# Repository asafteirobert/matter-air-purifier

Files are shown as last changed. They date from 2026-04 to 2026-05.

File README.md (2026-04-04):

# Matter Air Purifier

Firmware for a CRBox air purifier built around the Seeed Studio XIAO ESP32C6. Controllable via **Matter over Thread**. Integrates well and can be commissioned in Home Assistant. Since the device is not certified, commissioning with other platforms such as Apple Home and Google Home likely does not work directly.

> For an experimental version without Matter that hosts a local web server with a web UI, see the [standalone-mode](../../tree/standalone-mode) branch.

## Hardware

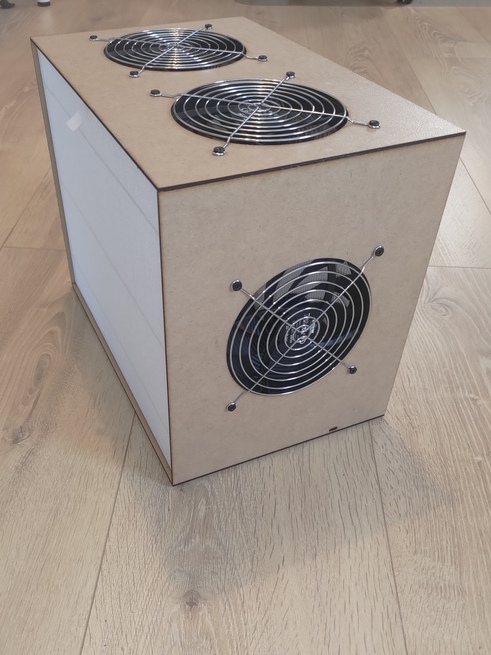
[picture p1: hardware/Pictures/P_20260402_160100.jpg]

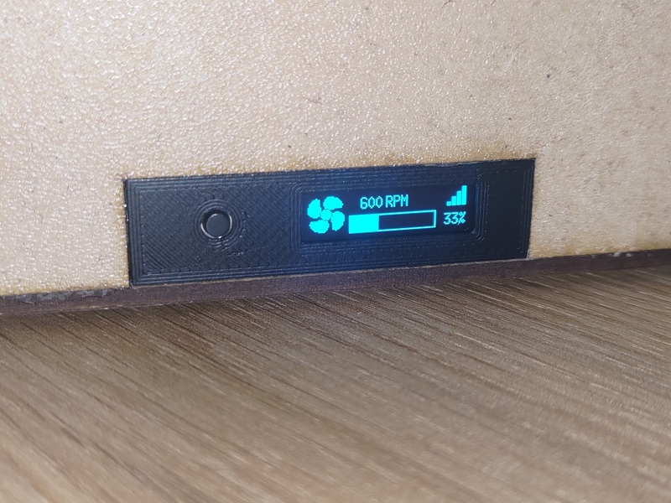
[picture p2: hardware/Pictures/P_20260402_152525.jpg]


The CRBox is designed for 2 IKEA STARKVIND filters. It has 3 **140mm BeQuiet Pure Wings 3 High Speed** fans which offer extremely quiet operation at low speeds.
The case is made from laser-cut MDF and smoothed 7mm pine strips, glued with epoxy. A small 3D printed part is used as a front panel. It's powered though USB C. It requires a 12V capable USB-PD power supply (IKEA 20W SJÖSS works great).

## Performance
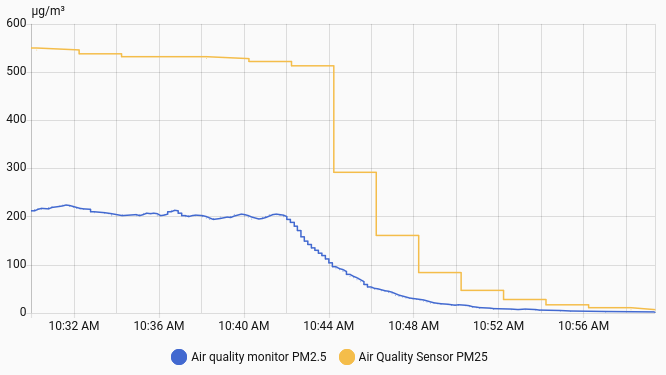
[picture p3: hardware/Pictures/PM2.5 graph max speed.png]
PM2.5 graph at 100% speed


Limited testing shows the Air Purifier can bring an extremely polluted room from ~400 ug/m3 PM2.5 to <10 ug/m3
- in 4 hours at 12% speed.
- in 53 minutes at 50% speed.
- in 17 minutes at 100% speed.

## Making your own
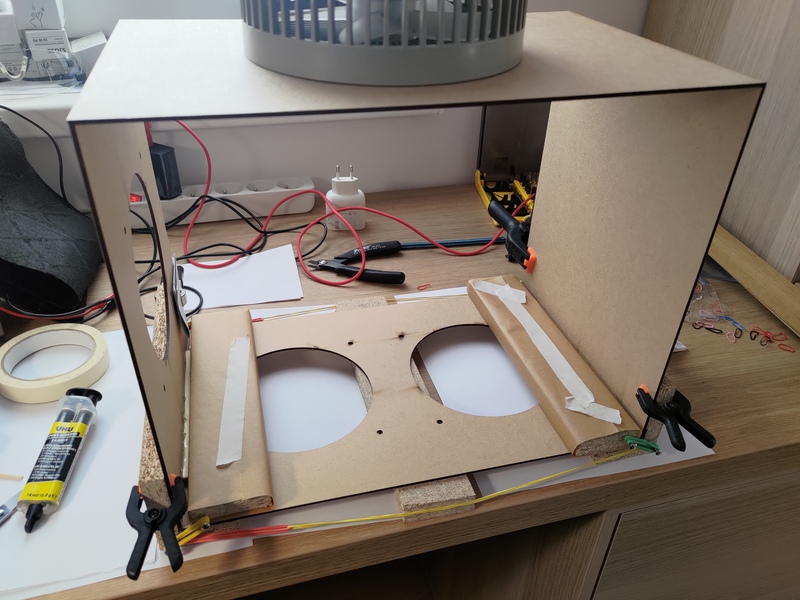
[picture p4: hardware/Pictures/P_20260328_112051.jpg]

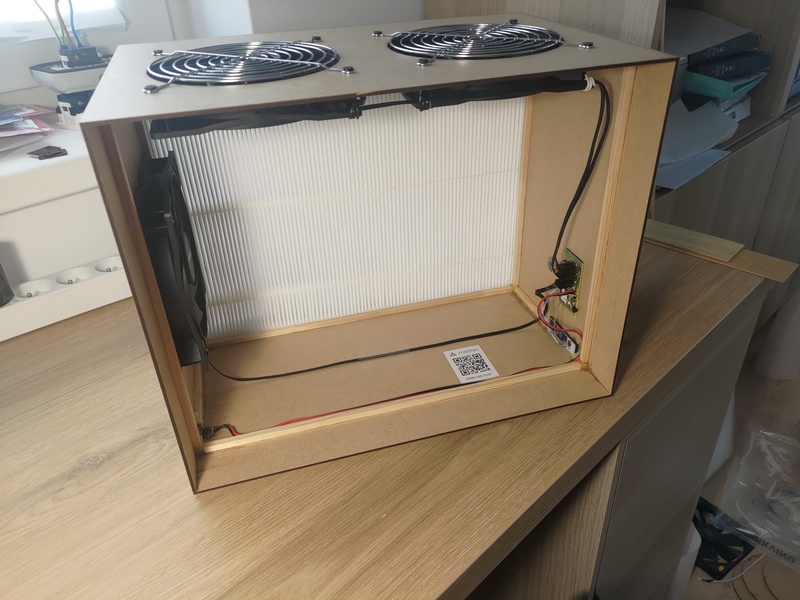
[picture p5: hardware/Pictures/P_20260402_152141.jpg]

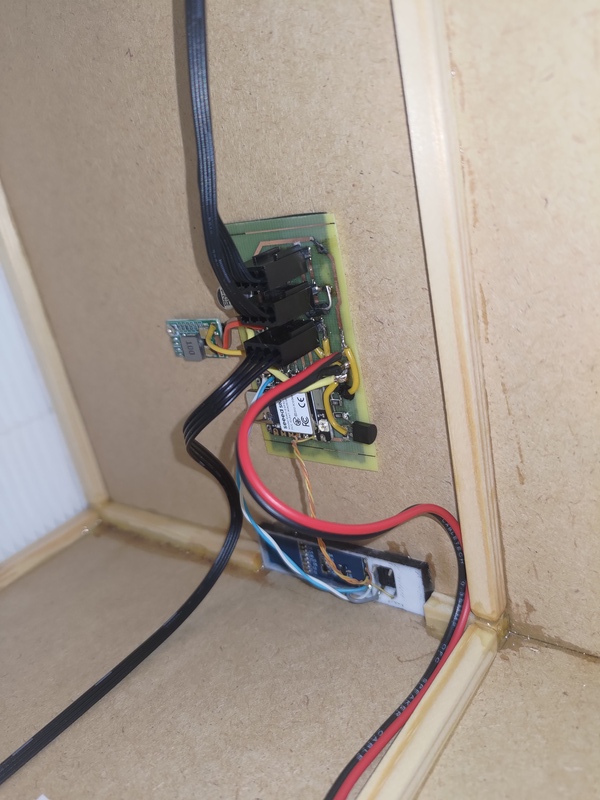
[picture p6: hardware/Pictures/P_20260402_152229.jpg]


This is a hobby project. I'm sharing this to serve as inspiration for anyone that wants to build something similar. Assembly is quite involved and I'm not providing step by step instructions but I'm sharing all the relevant files. See [hardware](hardware/)

## Features

- **Matter Air Purifier device type** — Fan Control cluster with Off/Low/Medium/High modes and 0–100% speed control
- **3-fan control** — PWM speed control (25 kHz) with per-fan RPM tachometer feedback
- **OLED display** — 128×32 screen showing fan speed, RPM, signal bars, QR code for commissioning, and info/reset screens
- **Physical buttons** — Short press toggles Off/Low/Medium/High; 2 second long press shows info screen. 8 second long press triggers factory reset.
- **Thread-only** — Runs on the ESP32-C6's 802.15.4 radio; WiFi disabled (see [Enabling WiFi](#enabling-wifi-alongside-thread))
- **OTA updates** — Firmware updates via Home Assistant Matter Server
- **Factory NVS partition** — Stores per-device commissioning codes, QR codes

## Commissioning

Use the scripts in `mfg-tool-scripts/` to generate and flash per-device commissioning data:

```bash
./0_clean.sh      # remove previous outputs
./1_generate.sh   # generate new commissioning data
./2_add_qrcode.sh # embed QR and manual pairing codes
./3_flash.sh      # flash to device (default port: /dev/ttyACM0)
```

Override the port: `PORT=/dev/ttyUSB0 ./3_flash.sh`.

Commissioning QR code and manual code will be shown on the tiny screen when the commissioning window is open, but it will be hard to scan. A png of the QR code can be found in `mfg-tool-scripts/out/fff1_8002/<hash>/<hash>-qrcode.png`

## OTA Update via Home Assistant Matter Server

1. Bump `CONFIG_DEVICE_SOFTWARE_VERSION` / `CONFIG_DEVICE_SOFTWARE_VERSION_NUMBER` in `sdkconfig.defaults.esp32c6`
2. Bump `PROJECT_VER` / `PROJECT_VER_NUMBER` in `CMakeLists.txt`
3. Build and compute the OTA checksum:
   ```bash
   openssl dgst -sha256 -binary matter-air-purifier-ota.bin | base64
   ```
4. Copy `matter-air-purifier-ota.bin` to:
   `/addon_configs/core_matter_server/updates/matter-air-purifier-ota.ota`
5. Create `matter-air-purifier-ota.json`:
   ```json
   {
     "modelVersion": {
       "vid": 65521,
       "pid": 32769,
       "softwareVersion": <VERSION>,
       "softwareVersionString": "<VERSION STRING>",
       "cdVersionNumber": 1,
       "softwareVersionValid": true,
       "otaUrl": "file:///matter-air-purifier-ota.ota",
       "otaChecksum": "<CHECKSUM>",
       "otaChecksumType": 1,
       "minApplicableSoftwareVersion": 0,
       "maxApplicableSoftwareVersion": <PREVIOUS VERSION>,
       "releaseNotesUrl": ""
     }
   }
   ```
6. Trigger the update from the Matter Server web UI by selecting the node in the sidebar.

## Enabling WiFi alongside Thread

The ESP32-C6 has separate radios for 802.15.4 (Thread) and WiFi, so both can run simultaneously. WiFi is disabled by default because it increases RAM/flash usage and the WiFi radio stays powered even when idle (no credentials commissioned).

To enable WiFi as a secondary network interface:

1. In `sdkconfig.defaults.esp32c6`, change:
   ```
   CONFIG_ENABLE_WIFI_STATION=n
   ```
   to:
   ```
   CONFIG_ENABLE_WIFI_STATION=y
   ```

2. Switch mDNS to the platform implementation (required for Thread DNS-SD):
   ```
   CONFIG_USE_MINIMAL_MDNS=n
   ```
   > **Note:** The platform mDNS backend (`ESP32DnssdImpl.cpp`) currently has build errors (ignored `CHIP_ERROR` returns treated as fatal by `-Werror`). If the build fails, set `CONFIG_USE_MINIMAL_MDNS=y` as a workaround until the upstream SDK is fixed.

3. Rebuild and reflash.

## AI Disclaimer
This project was coded with heavy use of Claude Code

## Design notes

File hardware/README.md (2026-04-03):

# Hardware

- **3D model** can be seen [here](https://a360.co/4dngQW1). Free license does not allow me to export it.
- **[Laser cut](Laser%20cut/)** — DXF files to laser cut the 2.5mm MDF boards making most of the body. Using a different thickness means some dimensions will change.
- **[Schematic](Schematic/)** — Schematic, PCB and EasyEDA Pro project. The PCB was manufactured at home with only the top side, so some connections use wires. This is why some of the routing, large vias and DRC rules look strange.
- **[Front Panel](Front%20Panel/)** — 3D model to be 3D printed, that slots in the front panel. It has slots for a microswitch and a common 128x32 OLED display.
- **[Pictures](Pictures/)** — Photos of the hardware.

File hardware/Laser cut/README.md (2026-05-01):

**[version 1](version%201/)** contains the first version, visible in the pictures with the fan on the back. The latest version has the fan in the front.

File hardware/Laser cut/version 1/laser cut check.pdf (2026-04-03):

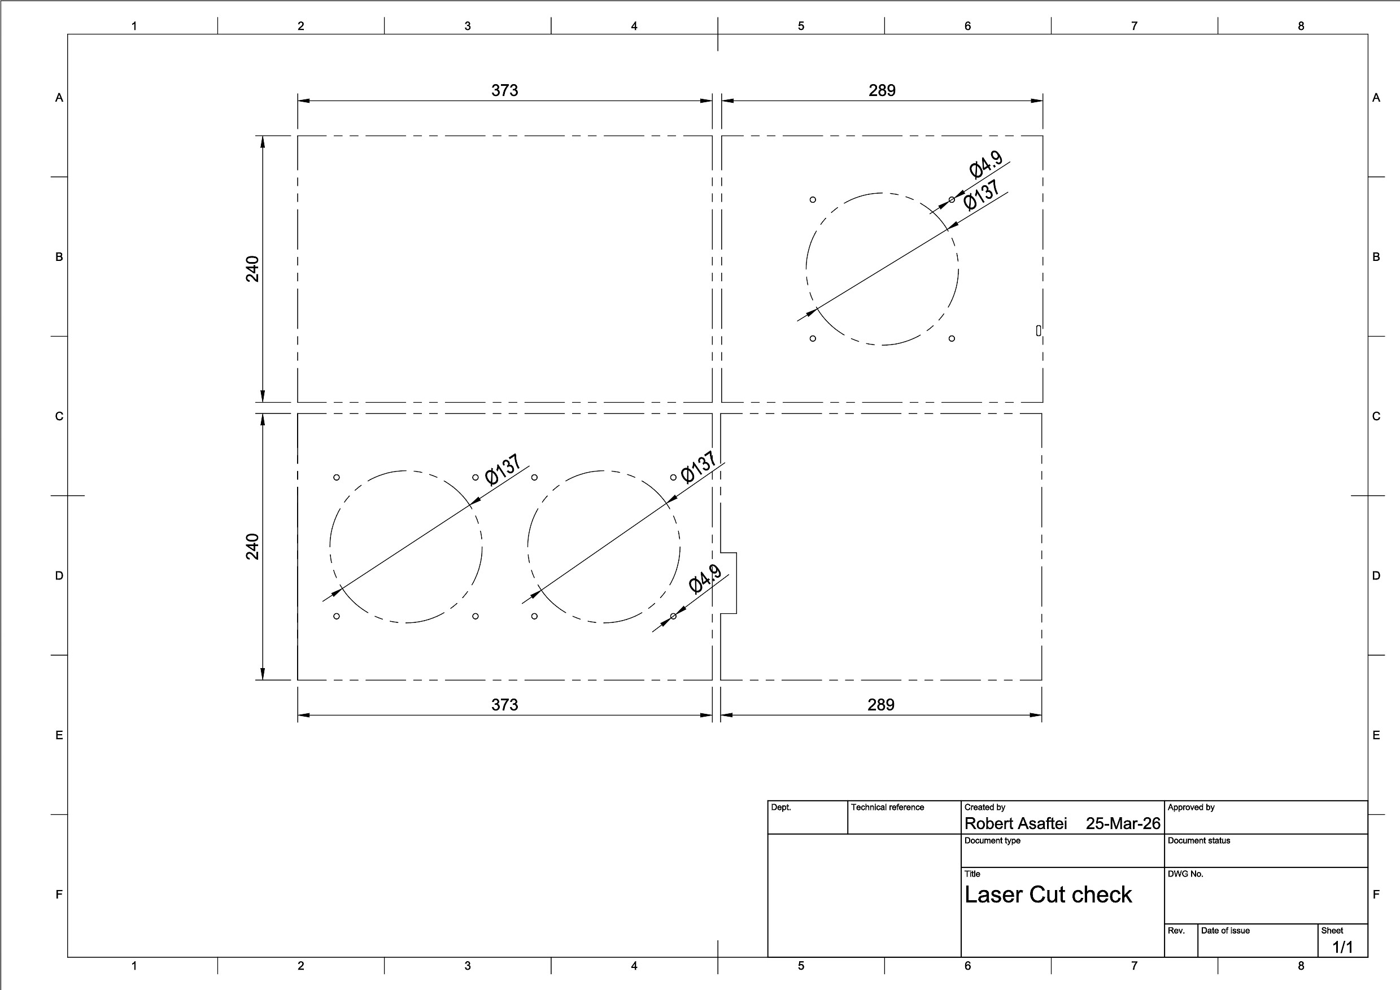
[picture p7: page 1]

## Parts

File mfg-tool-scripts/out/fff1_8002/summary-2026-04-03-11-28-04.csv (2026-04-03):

discriminator | iteration-count | salt | vendor-id | vendor-name | product-id | product-name | hardware-ver | hw-ver-str | serial-num | verifier | pincode | qrcode | manualcode
2458 | 10000 | CpgTCc8W+Rcqdphdbbo67YKkOLRqsWQs+q+SB6Ub92I= | 65521 | Twinsen | 32770 | Air Purifier | 1 | 01 | d155618ca8cd4e3e44d1683ac4f1faaf | hWKX0owqHqvmHICCKsJPmoxauj6mCclDcPf6ccEDxU0ENnAkcprttOtbRf4fQ4uoTI6fEox0D49rsdVOc2k7ParbnqoPTJrCTLCj90Uca5rc46i5cfkHWGtDyjAfElME3g== | 96988228 | MT:06PS0KQS02RINU6X120 | 2277-165-9195

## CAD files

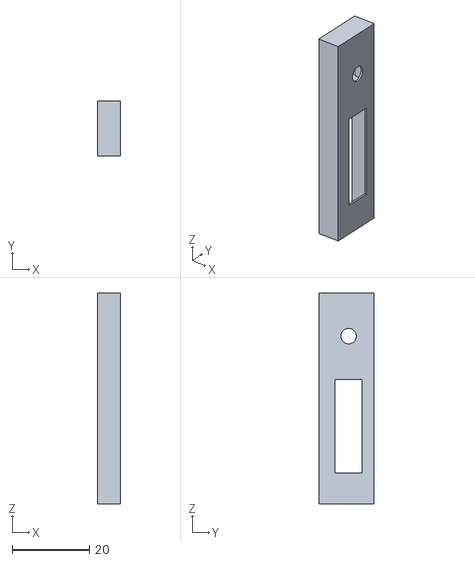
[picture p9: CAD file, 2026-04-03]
hardware/Front Panel/CRBox Front Panel.stl
6.00 x 14.2 x 54.6

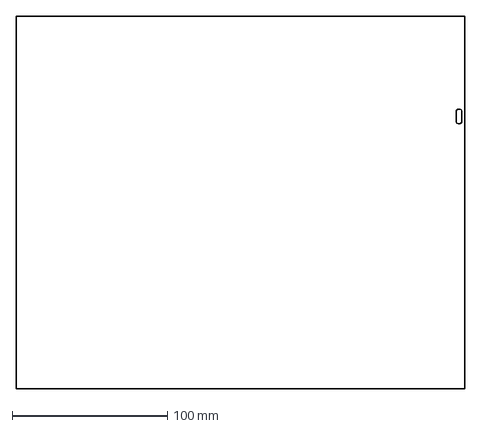
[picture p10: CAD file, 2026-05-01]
hardware/Laser cut/laser cut left.dxf
289.0 x 240.0 mm

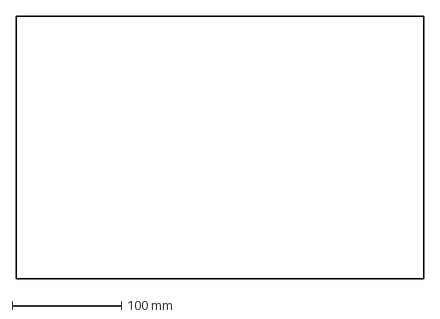
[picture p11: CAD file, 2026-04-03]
hardware/Laser cut/version 1/laser cut bottom.dxf
373.0 x 240.0 mm

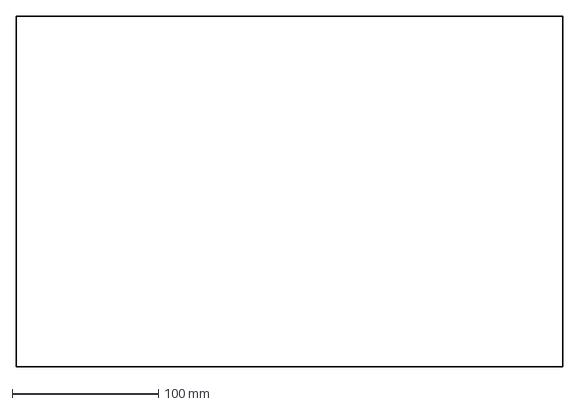
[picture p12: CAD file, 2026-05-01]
hardware/Laser cut/laser cut bottom.dxf
374.0 x 240.0 mm

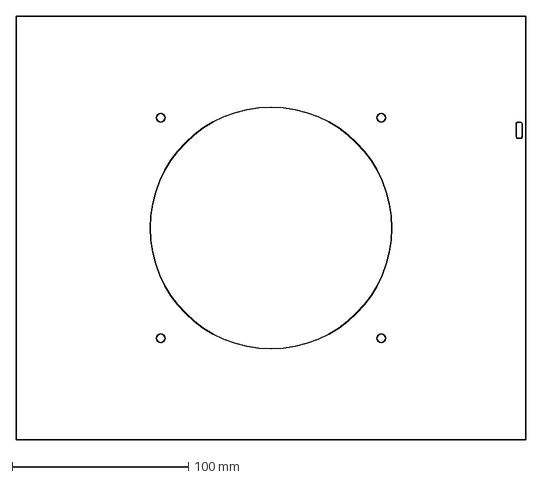
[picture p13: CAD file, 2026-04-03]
hardware/Laser cut/version 1/laser cut left.dxf
289.0 x 240.0 mm

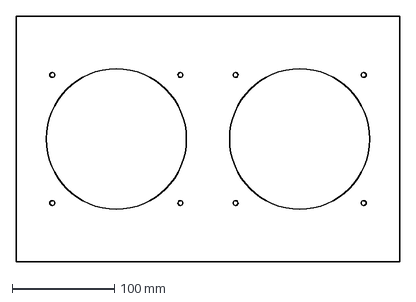
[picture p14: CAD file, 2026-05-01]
hardware/Laser cut/laser cut top.dxf
374.0 x 240.0 mm

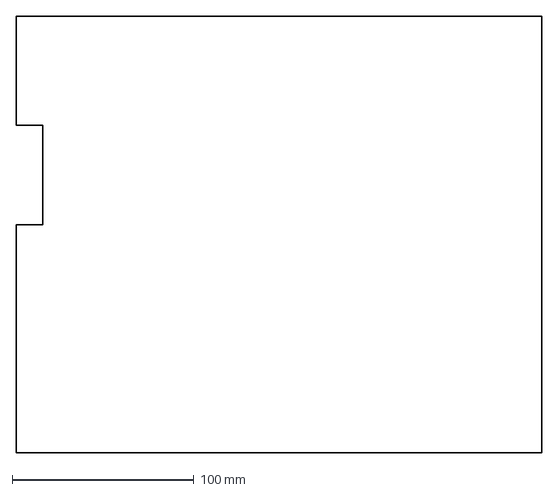
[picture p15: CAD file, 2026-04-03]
hardware/Laser cut/version 1/laser cut right.dxf
289.0 x 240.0 mm

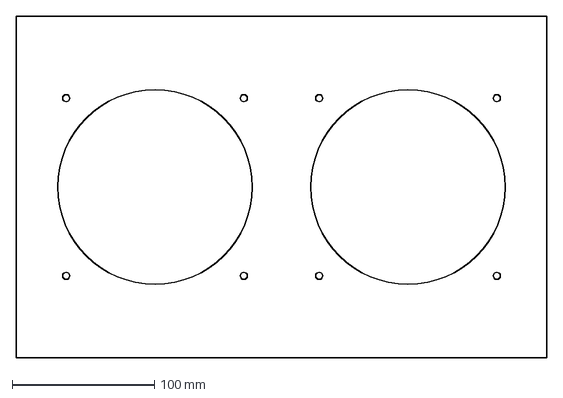
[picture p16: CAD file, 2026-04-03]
hardware/Laser cut/version 1/laser cut top.dxf
373.0 x 240.0 mm

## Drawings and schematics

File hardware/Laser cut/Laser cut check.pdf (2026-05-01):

240

# 240 Ø137 Ø137 Ø4.9

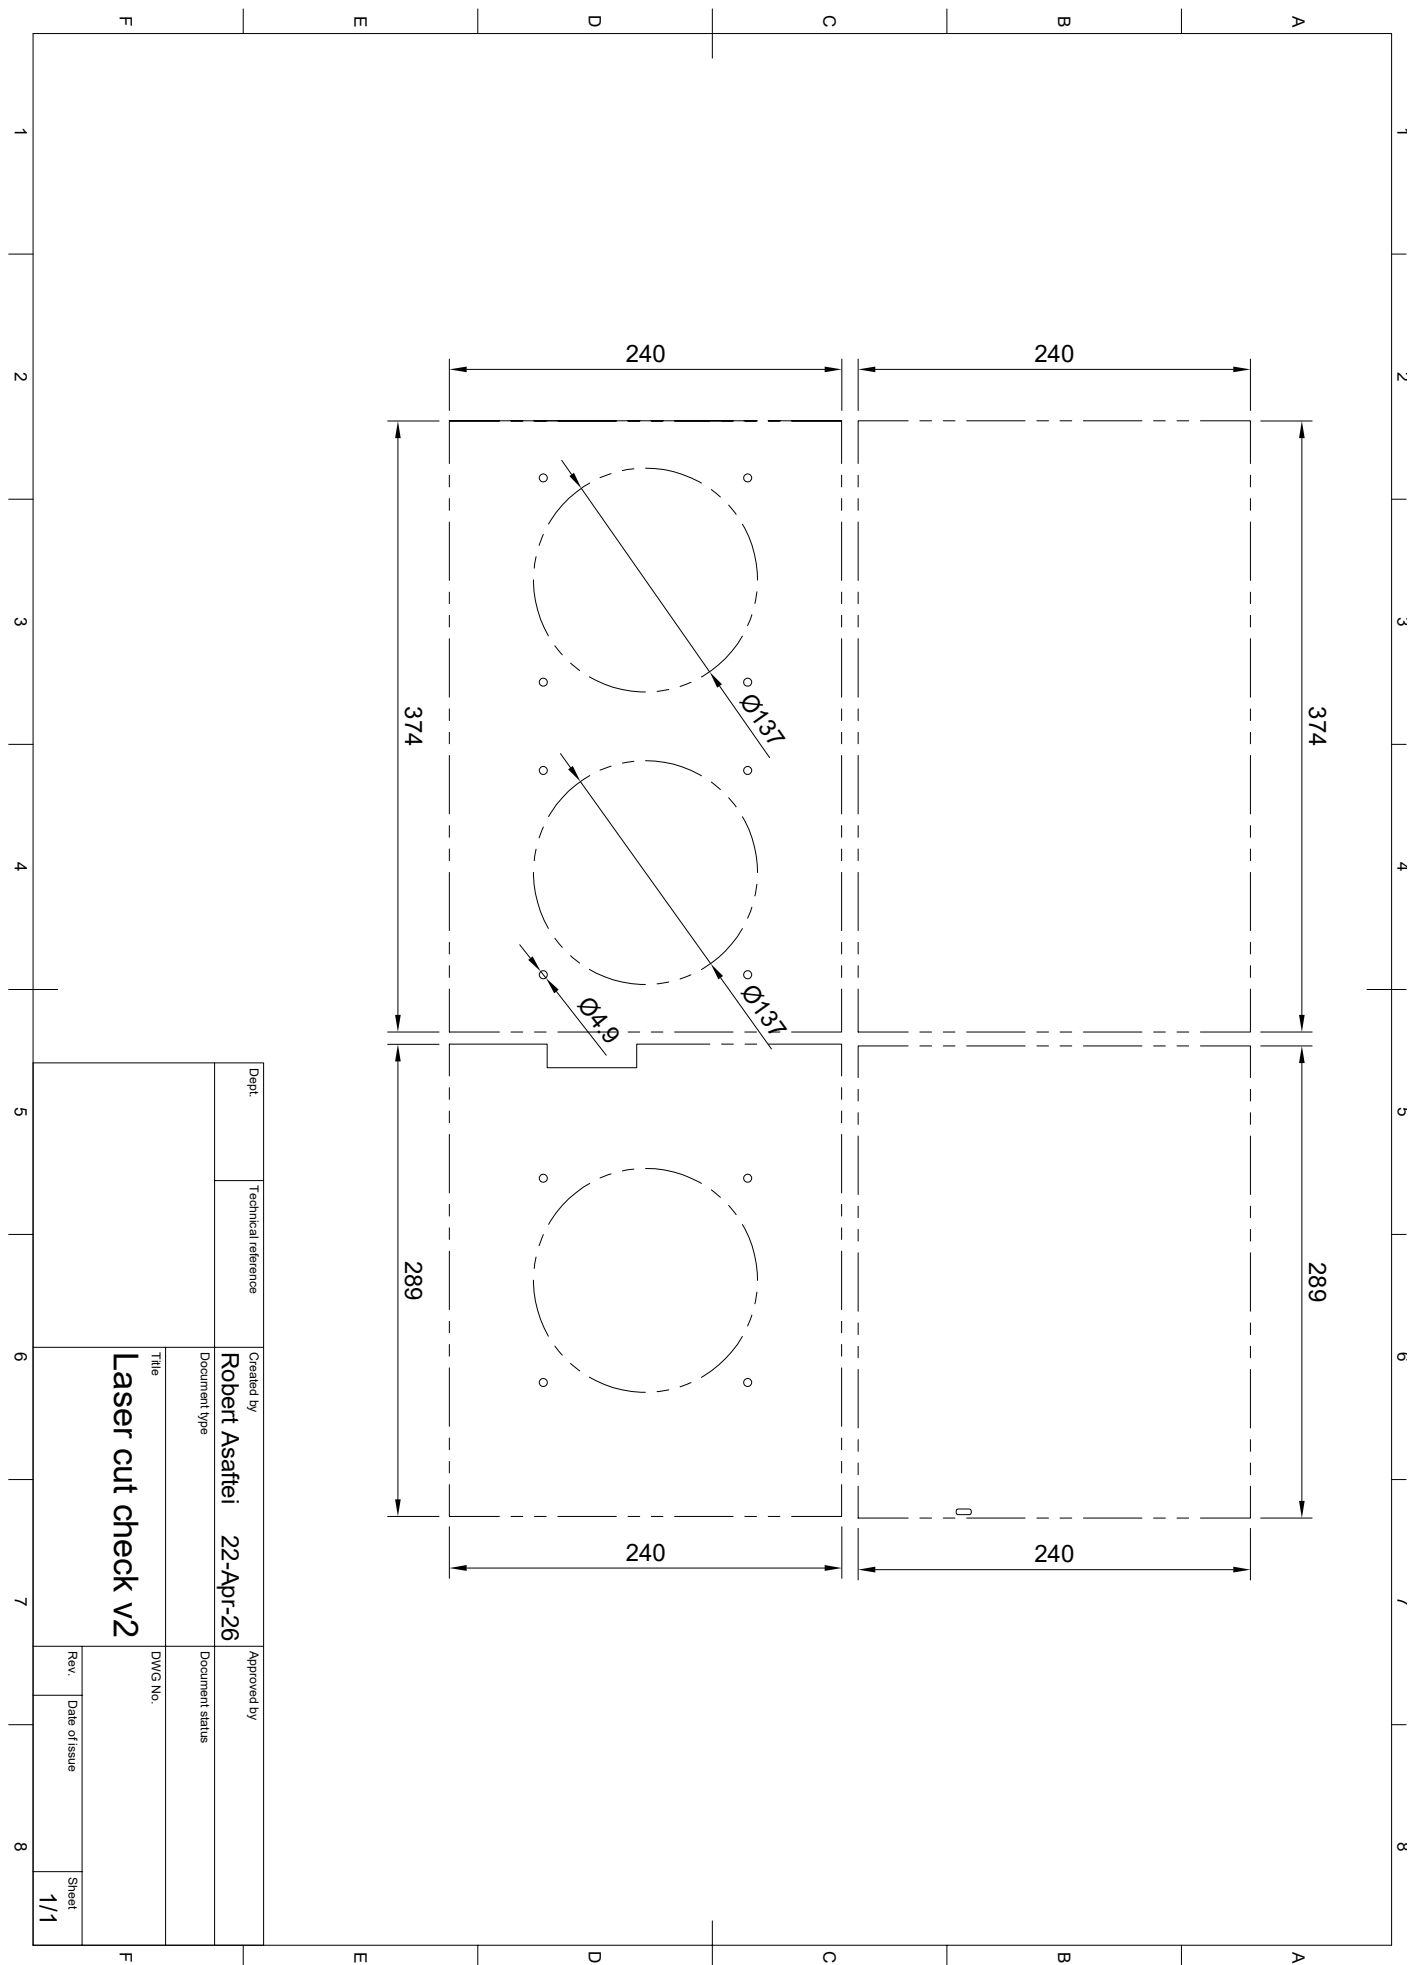
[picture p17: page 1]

1 A 2 3 4 5 6 7 8 1 2 3 4 5 6 7 8 FEDCB FEDCBA Dept. Technical reference Created by Approved by Title DWG No. Document type Document status Rev. Date of issue Sheet 22-Apr-26 1/1 Laser cut check v2 Robert Asaftei 374 289

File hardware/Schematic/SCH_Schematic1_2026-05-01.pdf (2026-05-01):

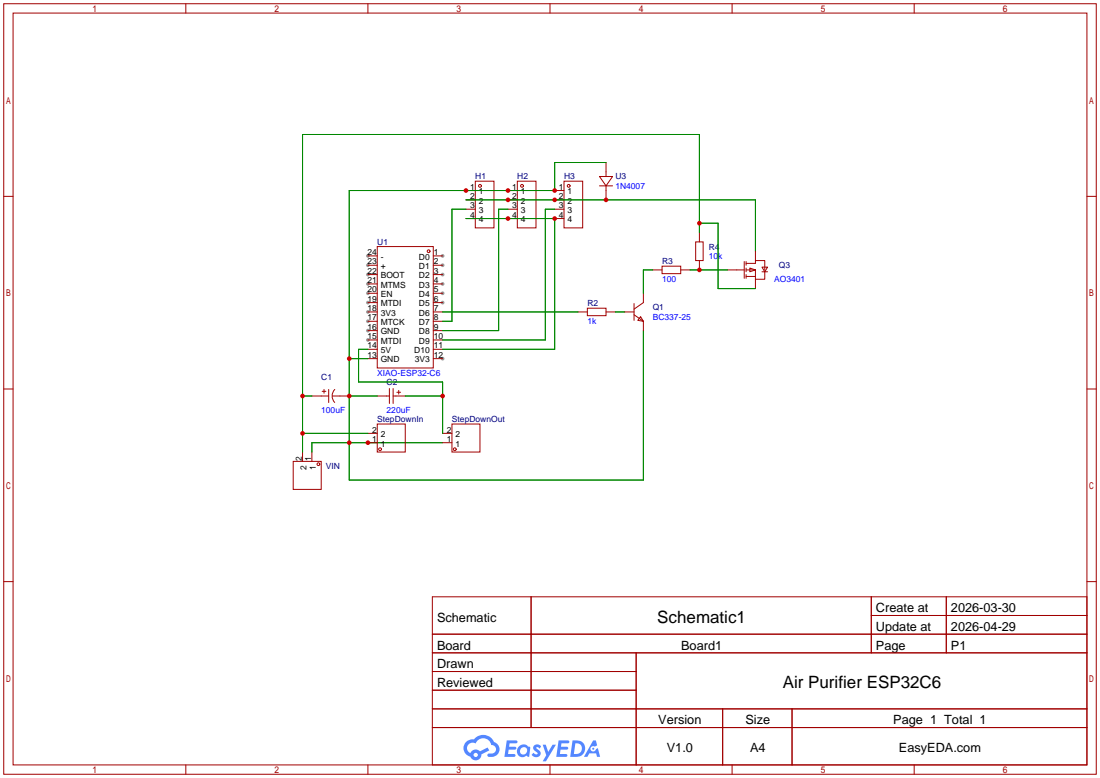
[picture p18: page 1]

3V3 12 GND 13 5V 14 MTDI 15 GND 16 MTCK 17 3V3 18 MTDI 19 EN 20 MTMS 21 BOOT 22 +

Schematic | Schematic1 | Create at | 2026-03-30

Update at | 2026-04-29

Board | Board1 | Page | P1
Drawn | | Air Purifier ESP32C6
Reviewed

Version | Size | Page 1 Total 1
V1.0 | A4 | EasyEDA.com

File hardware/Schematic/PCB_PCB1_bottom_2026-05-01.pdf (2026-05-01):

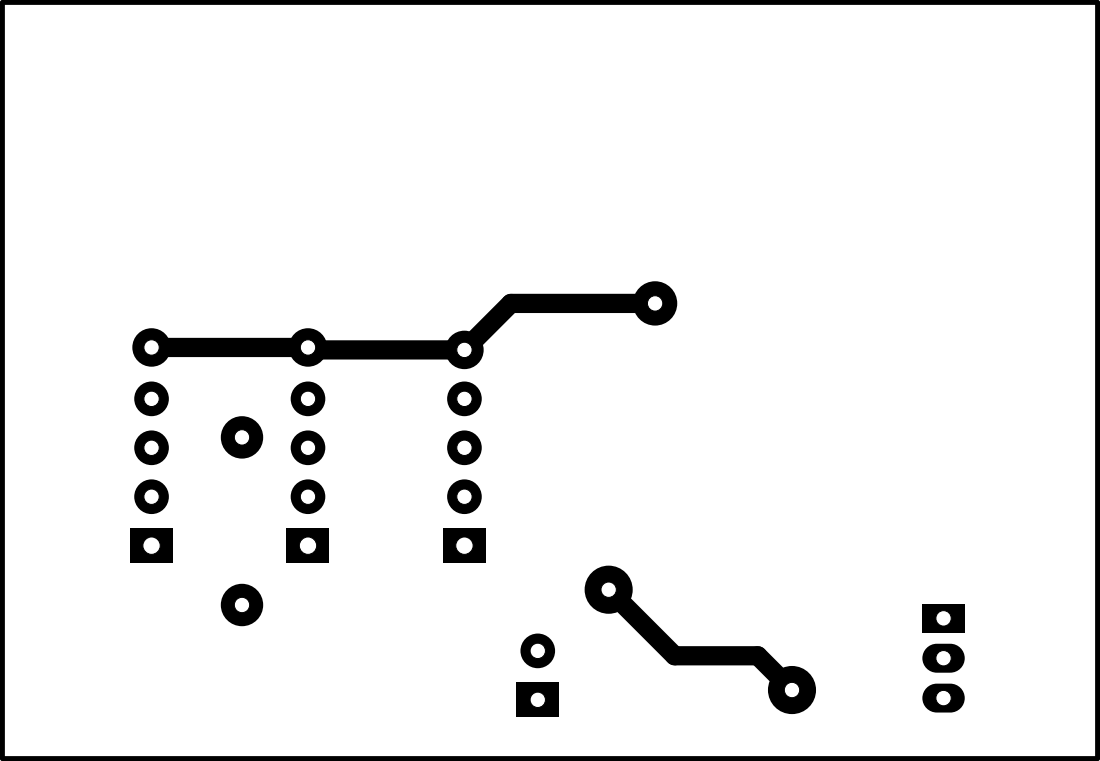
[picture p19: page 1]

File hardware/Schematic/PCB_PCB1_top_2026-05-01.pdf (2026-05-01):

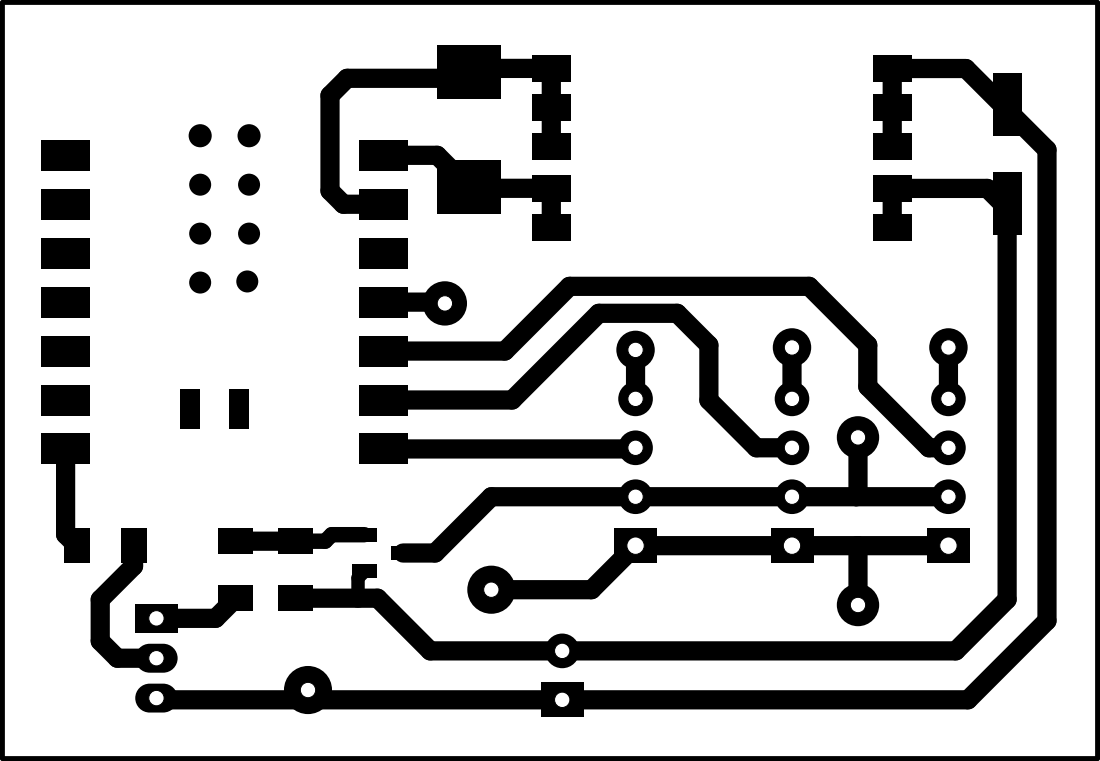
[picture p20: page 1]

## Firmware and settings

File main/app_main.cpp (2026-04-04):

#include <esp_err.h>
#include <esp_log.h>
#include <nvs_flash.h>
#include "freertos/FreeRTOS.h"
#include "freertos/task.h"

#include <esp_matter.h>
#include <esp_matter_console.h>
#include <esp_matter_ota.h>

#include "CliCommands.hpp"

#include "ButtonDriver.hpp"
#include "FanDriver.hpp"
#include "DisplayDriver.hpp"

#include "Utils.hpp"

#if CHIP_DEVICE_CONFIG_ENABLE_THREAD
#include <platform/ESP32/OpenthreadLauncher.h>
#include <esp_openthread.h>
#include <esp_openthread_lock.h>
#include <openthread/thread.h>
#endif

#include "esp_timer.h"

#include <app/server/CommissioningWindowManager.h>
#include <app/server/Server.h>
#include <nvs.h>

#ifdef CONFIG_ENABLE_SET_CERT_DECLARATION_API
#include <esp_matter_providers.h>
#include <lib/support/Span.h>
#ifdef CONFIG_SEC_CERT_DAC_PROVIDER
#include <platform/ESP32/ESP32SecureCertDACProvider.h>
#elif defined(CONFIG_FACTORY_PARTITION_DAC_PROVIDER)
#include <platform/ESP32/ESP32FactoryDataProvider.h>
#endif
using namespace chip::DeviceLayer;
#endif

using namespace esp_matter;
using namespace esp_matter::attribute;
using namespace esp_matter::endpoint;
using namespace chip::app::Clusters;

static const char *TAG = "app_main";
constexpr auto k_timeout_seconds = 300;

ButtonDriver buttonDriver;
FanDriver fanDriver;
DisplayDriver displayDriver;

#ifdef CONFIG_ENABLE_SET_CERT_DECLARATION_API
extern const uint8_t cd_start[] asm("_binary_certification_declaration_der_start");
extern const uint8_t cd_end[] asm("_binary_certification_declaration_der_end");

const chip::ByteSpan cdSpan(cd_start, static_cast<size_t>(cd_end - cd_start));
#endif // CONFIG_ENABLE_SET_CERT_DECLARATION_API

#if CONFIG_ENABLE_ENCRYPTED_OTA
extern const char decryption_key_start[] asm("_binary_esp_image_encryption_key_pem_start");
extern const char decryption_key_end[] asm("_binary_esp_image_encryption_key_pem_end");

static const char *s_decryption_key = decryption_key_start;
static const uint16_t s_decryption_key_len = decryption_key_end - decryption_key_start;
#endif // CONFIG_ENABLE_ENCRYPTED_OTA

static void app_event_cb(const ChipDeviceEvent *event, intptr_t arg)
{
    switch (event->Type) 
    {
    case chip::DeviceLayer::DeviceEventType::kInterfaceIpAddressChanged:
        ESP_LOGI(TAG, "Interface IP Address changed");
        break;

    case chip::DeviceLayer::DeviceEventType::kCommissioningComplete:
        if (displayDriver.getActiveScreen() == DisplayDriver::Screen::Comission)
            displayDriver.setActiveScreen(DisplayDriver::Screen::Main);
        ESP_LOGI(TAG, "Commissioning complete");
        break;

    case chip::DeviceLayer::DeviceEventType::kFailSafeTimerExpired:
        ESP_LOGI(TAG, "Commissioning failed, fail safe timer expired");
        break;

    case chip::DeviceLayer::DeviceEventType::kCommissioningSessionStarted:
        ESP_LOGI(TAG, "Commissioning session started");
        break;

    case chip::DeviceLayer::DeviceEventType::kCommissioningSessionStopped:
        ESP_LOGI(TAG, "Commissioning session stopped");
        break;

    case chip::DeviceLayer::DeviceEventType::kCommissioningWindowOpened:
    {
        displayDriver.setActiveScreen(DisplayDriver::Screen::Comission);
        ESP_LOGI(TAG, "Commissioning window opened");
        break;
    }

    case chip::DeviceLayer::DeviceEventType::kCommissioningWindowClosed:
    {
        if (displayDriver.getActiveScreen() == DisplayDriver::Screen::Comission)
            displayDriver.setActiveScreen(DisplayDriver::Screen::Main);
        ESP_LOGI(TAG, "Commissioning window closed");
        break;
    }

    case chip::DeviceLayer::DeviceEventType::kFabricRemoved: 
    {
        ESP_LOGI(TAG, "Fabric removed successfully");
        if (chip::Server::GetInstance().GetFabricTable().FabricCount() == 0) 
        {
            chip::CommissioningWindowManager  &commissionMgr = chip::Server::GetInstance().GetCommissioningWindowManager();
            constexpr auto kTimeoutSeconds = chip::System::Clock::Seconds16(k_timeout_seconds);
            if (!commissionMgr.IsCommissioningWindowOpen())
            {
                /* After removing last fabric, we do not remove the Wi-Fi credentials
                 * and still has IP connectivity so, only advertising on DNS-SD.
                 */
                CHIP_ERROR err = commissionMgr.OpenBasicCommissioningWindow(kTimeoutSeconds,
                                                                            chip::CommissioningWindowAdvertisement::kDnssdOnly);
                if (err != CHIP_NO_ERROR)
                {
                    ESP_LOGE(TAG, "Failed to open commissioning window, err:%" CHIP_ERROR_FORMAT, err.Format());
                }
            }
        }
        break;
    }

    case chip::DeviceLayer::DeviceEventType::kFabricWillBeRemoved:
        ESP_LOGI(TAG, "Fabric will be removed");
        break;

    case chip::DeviceLayer::DeviceEventType::kFabricUpdated:
        ESP_LOGI(TAG, "Fabric is updated");
        break;

    case chip::DeviceLayer::DeviceEventType::kFabricCommitted:
        ESP_LOGI(TAG, "Fabric is committed");
        break;

    case chip::DeviceLayer::DeviceEventType::kBLEDeinitialized:
        ESP_LOGI(TAG, "BLE deinitialized and memory reclaimed");
        break;

    default:
        break;
    }
}

// This callback is invoked when clients interact with the Identify Cluster.
// In the callback implementation, an endpoint can identify itself. (e.g., by flashing an LED or light).
static esp_err_t app_identification_cb(identification::callback_type_t type, uint16_t endpoint_id, uint8_t effect_id,
                                       uint8_t effect_variant, void *priv_data)
{
    ESP_LOGI(TAG, "Identification callback: type: %u, effect: %u, variant: %u", type, effect_id, effect_variant);
    if (type == identification::START || type == identification::EFFECT)
    {
        displayDriver.setActiveScreen(DisplayDriver::Screen::Identify);
    }
    return ESP_OK;
}

/**
 * Called by the Matter stack BEFORE (PRE_UPDATE) and AFTER (POST_UPDATE) an
 * attribute is written.  We only need PRE_UPDATE to drive the hardware.
 */
static esp_err_t app_attribute_update_cb(attribute::callback_type_t type,
                                         uint16_t  endpoint_id,
                                         uint32_t  cluster_id,
                                         uint32_t  attribute_id,
                                         esp_matter_attr_val_t *val,
                                         void *priv_data)
{
    //ESP_LOGI(TAG, "app_attribute_update_cb type: %d, endpoint_id: %d, cluster_id: %d, attribute_id: %d, val.u8: %d", 
    //              type,
    //              endpoint_id, 
    //              cluster_id, 
    //              attribute_id, 
    //              (val) ? val->val.u8 : -1);

    return fanDriver.attributeUpdate(type, endpoint_id, cluster_id, attribute_id, val);
}

static void signalTimerCb(void * /*arg*/)
{
#if CHIP_DEVICE_CONFIG_ENABLE_THREAD
    if (esp_openthread_lock_acquire(pdMS_TO_TICKS(100)))
    {
        otInstance   *instance = esp_openthread_get_instance();
        otDeviceRole  role     = otThreadGetDeviceRole(instance);
        int8_t        rssi     = -120;
        bool          valid    = false;

        if (role == OT_DEVICE_ROLE_CHILD)
        {
            valid = (otThreadGetParentAverageRssi(instance, &rssi) == OT_ERROR_NONE);
        }
        else if (role == OT_DEVICE_ROLE_ROUTER || role == OT_DEVICE_ROLE_LEADER)
        {
            otNeighborInfoIterator it = OT_NEIGHBOR_INFO_ITERATOR_INIT;
            otNeighborInfo         info;
            while (otThreadGetNextNeighborInfo(instance, &it, &info) == OT_ERROR_NONE)
            {
                if (!info.mIsChild && info.mAverageRssi > rssi)
                    rssi = info.mAverageRssi;
            }
            valid = (rssi > -120);
        }

        esp_openthread_lock_release();

        //if (valid)
        //    ESP_LOGI(TAG, "Thread RSSI: %d dBm (role %d)", rssi, (int)role);
        //else
        //    ESP_LOGW(TAG, "Thread RSSI unavailable (role %d)", (int)role);

        DisplayDriver::ThreadRole displayRole;
        switch (role)
        {
            case OT_DEVICE_ROLE_CHILD:    displayRole = DisplayDriver::ThreadRole::Child;    break;
            case OT_DEVICE_ROLE_ROUTER:   displayRole = DisplayDriver::ThreadRole::Router;   break;
            case OT_DEVICE_ROLE_LEADER:   displayRole = DisplayDriver::ThreadRole::Leader;   break;
            case OT_DEVICE_ROLE_DETACHED: displayRole = DisplayDriver::ThreadRole::Detached; break;
            default:                      displayRole = DisplayDriver::ThreadRole::Disabled; break;
        }
        displayDriver.setThreadRole(displayRole);
        displayDriver.setSignal(rssi);
    }
#endif
}

extern "C" void app_main()
{
    esp_err_t err = ESP_OK;

    // Initialize the ESP NVS layer
    err = nvs_flash_init();
    if (err == ESP_ERR_NVS_NO_FREE_PAGES || err == ESP_ERR_NVS_NEW_VERSION_FOUND) {
        ESP_ERROR_CHECK(nvs_flash_erase());
        err = nvs_flash_init();
    }
    ESP_ERROR_CHECK(err);

    // Switch to internal antenna
    // Activate RF switch
    gpio_set_direction(ANTENNA_ENABLE_GPIO, GPIO_MODE_OUTPUT);
    gpio_set_level(ANTENNA_ENABLE_GPIO, 0); //active low

    // Select internal antenna
    gpio_set_direction(ANTENNA_CONFIG_GPIO, GPIO_MODE_OUTPUT);
    gpio_set_level(ANTENNA_CONFIG_GPIO, 0);

    displayDriver.init();
    displayDriver.drawSplashScreen();

    // Create a Matter node and add the mandatory Root Node device type on endpoint 0
    node::config_t node_config;

    // node handle can be used to add/modify other endpoints.
    node_t *node = node::create(&node_config, app_attribute_update_cb, app_identification_cb);
    ABORT_APP_ON_FAILURE(node != nullptr, ESP_LOGE(TAG, "Failed to create Matter node"));

    air_purifier::config_t air_purifier_config;
    air_purifier_config.fan_control.fan_mode          = (uint8_t)FanControl::FanModeEnum::kOff;
    air_purifier_config.fan_control.fan_mode_sequence = (uint8_t)FanControl::FanModeSequenceEnum::kOffLowMedHigh;

    endpoint_t *air_purifier_endpoint = air_purifier::create(node, &air_purifier_config, ENDPOINT_FLAG_NONE, nullptr);
    if (air_purifier_endpoint == nullptr)
    {
        ESP_LOGE(TAG, "Failed to create air purifier endpoint");
        return;
    }

    // Enable the MultiSpeed feature (required by Home Assistant for percentage control).
    // SpeedMax=100 makes SpeedSetting a direct 0-100 percentage.
    cluster_t *fan_cluster = cluster::get(air_purifier_endpoint, chip::app::Clusters::FanControl::Id);
    ABORT_APP_ON_FAILURE(fan_cluster != nullptr, ESP_LOGE(TAG, "Failed to get FanControl cluster"));
    cluster::fan_control::feature::multi_speed::config_t multispeed_config;
    multispeed_config.speed_max     = 100;
    multispeed_config.speed_setting = nullable<uint8_t>();   // null – no speed set yet
    multispeed_config.speed_current = 0;
    ABORT_APP_ON_FAILURE(cluster::fan_control::feature::multi_speed::add(fan_cluster, &multispeed_config) == ESP_OK,
                         ESP_LOGE(TAG, "Failed to add MultiSpeed feature"));

    uint16_t fanEndpointId = endpoint::get_id(air_purifier_endpoint);
    ESP_LOGI(TAG, "Air purifier endpoint created with endpoint id: %u", fanEndpointId);

    // Initialize drivers
    buttonDriver.init(fanEndpointId, displayDriver, fanDriver);
    fanDriver.init(fanEndpointId, displayDriver);

#if CHIP_DEVICE_CONFIG_ENABLE_THREAD && CHIP_DEVICE_CONFIG_ENABLE_WIFI_STATION
    // Enable secondary network interface
    secondary_network_interface::config_t secondary_network_interface_config;
    endpoint_t *secondary_endpoint = endpoint::secondary_network_interface::create(node, &secondary_network_interface_config, ENDPOINT_FLAG_NONE, nullptr);
    ABORT_APP_ON_FAILURE(secondary_endpoint != nullptr, ESP_LOGE(TAG, "Failed to create secondary network interface endpoint"));
#endif

#if CHIP_DEVICE_CONFIG_ENABLE_THREAD
    /* Set OpenThread platform config */
    esp_openthread_platform_config_t config = 
    {
        .radio_config = ESP_OPENTHREAD_DEFAULT_RADIO_CONFIG(),
        .host_config = ESP_OPENTHREAD_DEFAULT_HOST_CONFIG(),
        .port_config = ESP_OPENTHREAD_DEFAULT_PORT_CONFIG(),
    };
    set_openthread_platform_config(&config);
#endif

#ifdef CONFIG_ENABLE_SET_CERT_DECLARATION_API
    auto * dac_provider = get_dac_provider();
#ifdef CONFIG_SEC_CERT_DAC_PROVIDER
    static_cast<ESP32SecureCertDACProvider *>(dac_provider)->SetCertificationDeclaration(cdSpan);
#elif defined(CONFIG_FACTORY_PARTITION_DAC_PROVIDER)
    static_cast<ESP32FactoryDataProvider *>(dac_provider)->SetCertificationDeclaration(cdSpan);
#endif
#endif // CONFIG_ENABLE_SET_CERT_DECLARATION_API

    /* Matter start */
    err = esp_matter::start(app_event_cb);
    ABORT_APP_ON_FAILURE(err == ESP_OK, ESP_LOGE(TAG, "Failed to start Matter, err:%d", err));

    ESP_LOGI(TAG, "Matter started");
    fanDriver.syncFromMatter();

    // Read commissioning QR code from factory NVS for display
    {
        nvs_handle_t nvs;
        if (nvs_open("chip-factory", NVS_READONLY, &nvs) == ESP_OK)
        {
            char qrCodeBuf[128] = {};
            size_t len = sizeof(qrCodeBuf);
            if (nvs_get_str(nvs, "qrcode", qrCodeBuf, &len) == ESP_OK)
            {
                displayDriver.setCommissioningQRCode(qrCodeBuf);
            }
            else
            {
                ESP_LOGE(TAG, "QR code not found in factory NVS");
            }

            char manualCodeBuf[32] = {};
            len = sizeof(manualCodeBuf);
            if (nvs_get_str(nvs, "manualcode", manualCodeBuf, &len) == ESP_OK)
            {
                displayDriver.setCommissioningManualCode(manualCodeBuf);
            }
            else
            {
                ESP_LOGE(TAG, "Manual code not found in factory NVS");
            }

            nvs_close(nvs);
        }
    }

    esp_timer_handle_t signalTimer = nullptr;
    const esp_timer_create_args_t signalTimerArgs = {
        .callback = signalTimerCb,
        .arg      = nullptr,
        .name     = "signal_timer",
    };
    ESP_ERROR_CHECK(esp_timer_create(&signalTimerArgs, &signalTimer));
    ESP_ERROR_CHECK(esp_timer_start_periodic(signalTimer, 10 * 1000 * 1000 /* µs = 10 s */));
    signalTimerCb(nullptr);


#if CONFIG_ENABLE_ENCRYPTED_OTA
    err = esp_matter_ota_requestor_encrypted_init(s_decryption_key, s_decryption_key_len);
    ABORT_APP_ON_FAILURE(err == ESP_OK, ESP_LOGE(TAG, "Failed to initialized the encrypted OTA, err: %d", err));
#endif // CONFIG_ENABLE_ENCRYPTED_OTA

#if CONFIG_ENABLE_CHIP_SHELL
    esp_matter::console::diagnostics_register_commands();
    esp_matter::console::wifi_register_commands();
    esp_matter::console::factoryreset_register_commands();
    esp_matter::console::attribute_register_commands();
#if CONFIG_OPENTHREAD_CLI
    esp_matter::console::otcli_register_commands();
#endif
    cli_register_commands();
    esp_matter::console::init();
#endif

    ESP_LOGI(TAG, "Init finished");

    vTaskDelay(2000 / portTICK_PERIOD_MS);
    displayDriver.startTask();
    vTaskDelete(nullptr);
}

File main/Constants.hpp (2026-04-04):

#pragma once
#include "driver/gpio.h"

/** Status LED – lights when the fan is ON */
#define FAN_LED_GPIO    GPIO_NUM_15

/** on/off / Factory-reset button (active-LOW, internal pull-up) */
#define BOARD_BUTTON_GPIO     GPIO_NUM_9

/** interaction button (active-LOW, internal pull-up) */
#define PANEL_BUTTON_GPIO     GPIO_NUM_23

/** filter was changed button, reset the filter counter (active-LOW, internal pull-up) */
#define FILTER_RESET_BUTTON_GPIO     GPIO_NUM_2

/** PC fan PWM */
#define FAN_PWM_GPIO     GPIO_NUM_18

/** PC fan Mosfet for low-side switching */
#define FAN_POWER_GPIO     GPIO_NUM_16

/** PC fan 1 tachometer */
#define FAN1_TACH_GPIO     GPIO_NUM_20

/** PC fan 2 tachometer */
#define FAN2_TACH_GPIO     GPIO_NUM_19

/** PC fan 3 tachometer */
#define FAN3_TACH_GPIO     GPIO_NUM_17

/** RF switch power – must be driven LOW to enable antenna switching */
#define ANTENNA_ENABLE_GPIO     GPIO_NUM_3

/** RF switch select – LOW = internal ceramic antenna, HIGH = external antenna */
#define ANTENNA_CONFIG_GPIO GPIO_NUM_14

/** OLED screen SDA Pin*/
#define OLED_SDA_GPIO GPIO_NUM_22

/** OLED screen SCL Pin*/
#define OLED_SCL_GPIO GPIO_NUM_21

/** Filter usage maximum: 1 year at 600 RPM, 3 fans, 2 pulses/rev */
#define FILTER_MAX_USAGE (600ULL * 3ULL * 2ULL * 60ULL * 24ULL * 365ULL)



#if CHIP_DEVICE_CONFIG_ENABLE_THREAD
#include "esp_openthread_types.h"
#endif

#if CHIP_DEVICE_CONFIG_ENABLE_THREAD
#define ESP_OPENTHREAD_DEFAULT_RADIO_CONFIG()                                           \
    {                                                                                   \
        .radio_mode = RADIO_MODE_NATIVE,                                                \
    }

#define ESP_OPENTHREAD_DEFAULT_HOST_CONFIG()                                            \
    {                                                                                   \
        .host_connection_mode = HOST_CONNECTION_MODE_NONE,                              \
    }

#define ESP_OPENTHREAD_DEFAULT_PORT_CONFIG()                                            \
    {                                                                                   \
        .storage_partition_name = "nvs", .netif_queue_size = 10, .task_queue_size = 10, \
    }
#endif

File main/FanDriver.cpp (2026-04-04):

#include "FanDriver.hpp"

#include <esp_log.h>
#include <esp_matter.h>
#include <nvs.h>

// ── Range mapping for kOffLowMedHigh (Matter spec §4.4.6.3.1 / §4.4.6.6.1) ───
//
//  PercentSetting / SpeedSetting (SpeedMax=100, so both are identical values):
// The exact breakpoints are implementation-defined; the spec's own illustrative
// example uses equal thirds, which we adopt here.

static uint8_t percentToFanMode(uint8_t pct)
{
    using namespace chip::app::Clusters;
    if (pct == 0)   return (uint8_t)FanControl::FanModeEnum::kOff;
    if (pct <= 33)  return (uint8_t)FanControl::FanModeEnum::kLow;
    if (pct <= 66)  return (uint8_t)FanControl::FanModeEnum::kMedium;
    return                 (uint8_t)FanControl::FanModeEnum::kHigh;
}

// Default PercentSetting when switching to a mode without an existing in-range value.
// We use the top of each range so the fan runs at full power for the selected mode.
static uint8_t fanModeDefaultPercent(uint8_t fanMode)
{
    using namespace chip::app::Clusters;
    switch ((FanControl::FanModeEnum)fanMode)
    {
    case FanControl::FanModeEnum::kLow:    return 33;
    case FanControl::FanModeEnum::kMedium: return 66;
    case FanControl::FanModeEnum::kHigh:   return 100;
    default:                               return 0;
    }
}

// ── Helpers to update single attributes ────────

static void updateAttrU8(uint16_t endpoint, uint32_t cluster, uint32_t attr, uint8_t newVal)
{
    esp_matter_attr_val_t v = esp_matter_uint8(newVal);
    esp_matter::attribute::update(endpoint, cluster, attr, &v);
}

static void updateAttrEnum8(uint16_t endpoint, uint32_t cluster, uint32_t attr, uint8_t newVal)
{
    esp_matter_attr_val_t v = esp_matter_enum8(newVal);
    esp_matter::attribute::update(endpoint, cluster, attr, &v);
}
static void updateAttrNullableU8(uint16_t endpoint, uint32_t cluster, uint32_t attr, uint8_t newVal)
{
    esp_matter_attr_val_t v = esp_matter_nullable_uint8(nullable<uint8_t>(newVal));
    esp_matter::attribute::update(endpoint, cluster, attr, &v);
}


// ── Init ──────────────────────────────────────────────────────────────────────

void FanDriver::init(uint16_t fanEndpointId, DisplayDriver& displayDriver)
{
    this->fanEndpointId = fanEndpointId;
    this->displayDriver = &displayDriver;

    // Configure LEDC timer for 25 kHz (standard 4-pin PC fan PWM frequency)
    const ledc_timer_config_t timer_cfg = {
        .speed_mode      = PWM_SPEED_MODE,
        .duty_resolution = PWM_RESOLUTION,
        .timer_num       = PWM_TIMER,
        .freq_hz         = PWM_FREQ_HZ,
        .clk_cfg         = LEDC_AUTO_CLK,
    };
    ESP_ERROR_CHECK(ledc_timer_config(&timer_cfg));

    // Configure LEDC channel on the fan PWM pin, starting at 0% duty
    const ledc_channel_config_t channel_cfg = {
        .gpio_num   = FAN_PWM_GPIO,
        .speed_mode = PWM_SPEED_MODE,
        .channel    = PWM_CHANNEL,
        .intr_type  = LEDC_INTR_DISABLE,
        .timer_sel  = PWM_TIMER,
        .duty       = 0,
        .hpoint     = 0,
    };
    ESP_ERROR_CHECK(ledc_channel_config(&channel_cfg));

    // Configure power MOSFET gate pin – LOW = off, HIGH = on
    gpio_config_t power_gpio_cfg = {
        .pin_bit_mask = (1ULL << FAN_POWER_GPIO),
        .mode         = GPIO_MODE_OUTPUT,
        .pull_up_en   = GPIO_PULLUP_DISABLE,
        .pull_down_en = GPIO_PULLDOWN_DISABLE,
        .intr_type    = GPIO_INTR_DISABLE,
    };
    ESP_ERROR_CHECK(gpio_config(&power_gpio_cfg));
    gpio_set_level(FAN_POWER_GPIO, 0);  // off until a non-zero speed is set

    ESP_LOGI(TAG, "Fan driver initialised – PWM on GPIO %d at %lu Hz", FAN_PWM_GPIO, PWM_FREQ_HZ);

    // Configure PCNT units to count tachometer pulses (one per fan)
    const gpio_num_t tachGpios[3] = { FAN1_TACH_GPIO, FAN2_TACH_GPIO, FAN3_TACH_GPIO };
    for (int i = 0; i < 3; i++)
    {
        const pcnt_unit_config_t unit_cfg = {
            .low_limit  = -1,
            .high_limit = 32767,
        };
        ESP_ERROR_CHECK(pcnt_new_unit(&unit_cfg, &this->tachUnits[i]));

        const pcnt_chan_config_t chan_cfg = {
            .edge_gpio_num  = tachGpios[i],
            .level_gpio_num = -1,
        };
        pcnt_channel_handle_t chan = nullptr;
        ESP_ERROR_CHECK(pcnt_new_channel(this->tachUnits[i], &chan_cfg, &chan));
        // Count on rising edge only
        ESP_ERROR_CHECK(pcnt_channel_set_edge_action(chan,
            PCNT_CHANNEL_EDGE_ACTION_INCREASE,
            PCNT_CHANNEL_EDGE_ACTION_HOLD));

        // Reject glitch pulses shorter than 1 µs (noise from PWM switching)
        const pcnt_glitch_filter_config_t filter_cfg = {
            .max_glitch_ns = 1000,
        };
        ESP_ERROR_CHECK(pcnt_unit_set_glitch_filter(this->tachUnits[i], &filter_cfg));

        ESP_ERROR_CHECK(pcnt_unit_enable(this->tachUnits[i]));
        ESP_ERROR_CHECK(pcnt_unit_clear_count(this->tachUnits[i]));
        ESP_ERROR_CHECK(pcnt_unit_start(this->tachUnits[i]));
    }

    // 2-second periodic timer to sample pulse counts and log RPM
    const esp_timer_create_args_t timer_args = {
        .callback = &FanDriver::tachTimerCb,
        .arg      = this,
        .name     = "tach_timer",
    };
    ESP_ERROR_CHECK(esp_timer_create(&timer_args, &this->tachTimer));
    ESP_ERROR_CHECK(esp_timer_start_periodic(this->tachTimer, RPM_READ_INTERVAL_MS * 1000 /* µs */));

    // Load persisted filter usage counter
    nvs_handle_t nvs;
    if (nvs_open("app_data", NVS_READONLY, &nvs) == ESP_OK)
    {
        nvs_get_u64(nvs, "filter_cnt", &this->filterUsageCounter);
        nvs_close(nvs);
    }
    ESP_LOGI(TAG, "Filter usage counter loaded: %llu", (unsigned long long)this->filterUsageCounter);
    this->displayDriver->setFilterUsage(this->filterUsageCounter);
}

// ── Sync state from Matter NVS on startup ────────────────────────────────────
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

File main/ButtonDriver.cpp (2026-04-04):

#include "ButtonDriver.hpp"
#include "FanDriver.hpp"
#include "Constants.hpp"

#include <esp_err.h>
#include <esp_log.h>
#include <esp_matter.h>

void ButtonDriver::init(uint16_t fanEndpointId, DisplayDriver& displayDriver, FanDriver& fanDriver)
{
    this->fanEndpointId = fanEndpointId;
    this->displayDriver = &displayDriver;
    this->fanDriver     = &fanDriver;

    this->infoScreenEventArgs = { .long_press = { .press_time = 2000 } };
    this->factoryResetEventArgs = { .long_press = { .press_time = 8000 } };

    const button_config_t buttonConfig =
    {
        .long_press_time  = 2000,
        .short_press_time = 50,
    };
    const button_gpio_config_t boardButtonGpioConfig =
    {
        .gpio_num = BOARD_BUTTON_GPIO,
        .active_level = 0,
    };

    const button_gpio_config_t panelButtonGpioConfig =
    {
        .gpio_num = PANEL_BUTTON_GPIO,
        .active_level = 0,
    };

    if (iot_button_new_gpio_device(&buttonConfig, &boardButtonGpioConfig, &this->boardButtonHandle) != ESP_OK)
    {
        ESP_LOGE(TAG, "Failed to create button device");
        return;
    }

    esp_err_t err = ESP_OK;
    err |= iot_button_register_cb(this->boardButtonHandle, BUTTON_SINGLE_CLICK, NULL, buttonClickCallback, this);
    err |= iot_button_register_cb(this->boardButtonHandle, BUTTON_LONG_PRESS_START, &this->infoScreenEventArgs, buttonLongPressInfoCallback, this);
    err |= iot_button_register_cb(this->boardButtonHandle, BUTTON_LONG_PRESS_START, &this->factoryResetEventArgs, buttonLongPressFactoryResetCallback, this);
    err |= iot_button_register_cb(this->boardButtonHandle, BUTTON_PRESS_UP, NULL, buttonPressUpCallback, this);
    if (err != ESP_OK)
    {
        ESP_LOGE(TAG, "Failed to set button callbacks");
        return;
    }

    if (iot_button_new_gpio_device(&buttonConfig, &panelButtonGpioConfig, &this->panelButtonHandle) != ESP_OK)
    {
        ESP_LOGE(TAG, "Failed to create button device");
        return;
    }

    err = ESP_OK;
    err |= iot_button_register_cb(this->panelButtonHandle, BUTTON_SINGLE_CLICK, NULL, buttonClickCallback, this);
    err |= iot_button_register_cb(this->panelButtonHandle, BUTTON_LONG_PRESS_START, &this->infoScreenEventArgs, buttonLongPressInfoCallback, this);
    err |= iot_button_register_cb(this->panelButtonHandle, BUTTON_LONG_PRESS_START, &this->factoryResetEventArgs, buttonLongPressFactoryResetCallback, this);
    err |= iot_button_register_cb(this->panelButtonHandle, BUTTON_PRESS_UP, NULL, buttonPressUpCallback, this);
    if (err != ESP_OK)
    {
        ESP_LOGE(TAG, "Failed to set button callbacks");
        return;
    }

    // Filter reset button
    const button_gpio_config_t filterResetGpioConfig =
    {
        .gpio_num    = FILTER_RESET_BUTTON_GPIO,
        .active_level = 0,
    };
    if (iot_button_new_gpio_device(&buttonConfig, &filterResetGpioConfig, &this->filterResetButtonHandle) != ESP_OK)
    {
        ESP_LOGE(TAG, "Failed to create filter reset button device");
        return;
    }
    if (iot_button_register_cb(this->filterResetButtonHandle, BUTTON_SINGLE_CLICK, NULL, filterResetButtonCallback, this) != ESP_OK)
    {
        ESP_LOGE(TAG, "Failed to set filter reset button callback");
        return;
    }

    ESP_LOGI(TAG, "Buttons initialised");
    return;
}

void ButtonDriver::buttonClickCallback(void *handle, void *userData)
{
    using namespace chip::app::Clusters;

    ButtonDriver* thisInstance = (ButtonDriver*)userData;

    if (thisInstance->displayDriver->getActiveScreen() == DisplayDriver::Screen::Info ||
        thisInstance->displayDriver->getActiveScreen() == DisplayDriver::Screen::Comission)
    {
        ESP_LOGI(TAG, "Button click: return to main screen");
        thisInstance->displayDriver->setActiveScreen(DisplayDriver::Screen::Main);
        return;
    }

    ESP_LOGI(TAG, "Button click: toggle fan");
    uint16_t endpointId = thisInstance->fanEndpointId;
    uint32_t clusterId = FanControl::Id;
    uint32_t attributeId = FanControl::Attributes::FanMode::Id;

    esp_matter::attribute_t *attribute = esp_matter::attribute::get(endpointId, clusterId, attributeId);
    if (attribute == nullptr)
    {
        ESP_LOGE(TAG, "Failed to get FanMode attribute");
        return;
    }

    esp_matter_attr_val_t val = esp_matter_invalid(NULL);
    esp_matter::attribute::get_val(attribute, &val);
    // Toggle between presets
    val.val.u8 = (val.val.u8 == (uint8_t)FanControl::FanModeEnum::kOff) ? (uint8_t)FanControl::FanModeEnum::kLow
               : (val.val.u8 == (uint8_t)FanControl::FanModeEnum::kLow) ? (uint8_t)FanControl::FanModeEnum::kMedium
               : (val.val.u8 == (uint8_t)FanControl::FanModeEnum::kMedium) ? (uint8_t)FanControl::FanModeEnum::kHigh
               : (uint8_t)FanControl::FanModeEnum::kOff;
    esp_matter::attribute::update(endpointId, clusterId, attributeId, &val);
}

void ButtonDriver::buttonLongPressInfoCallback(void *handle, void *userData)
{
    ButtonDriver* thisInstance = (ButtonDriver*)userData;
    ESP_LOGI(TAG, "Button held 2s: show info screen");
    thisInstance->displayDriver->setActiveScreen(DisplayDriver::Screen::Info);
}

void ButtonDriver::buttonLongPressFactoryResetCallback(void *handle, void *userData)
{
    ButtonDriver* thisInstance = (ButtonDriver*)userData;
    ESP_LOGI(TAG, "Button held 8s: release to factory reset");
    thisInstance->performFactoryReset = true;
    thisInstance->displayDriver->setActiveScreen(DisplayDriver::Screen::FactoryReset);
}

void ButtonDriver::buttonPressUpCallback(void *handle, void *userData)
{
    ButtonDriver* thisInstance = (ButtonDriver*)userData;
    if (thisInstance->performFactoryReset)
    {
        ESP_LOGI(TAG, "Starting factory reset");
        esp_matter::factory_reset();
        thisInstance->performFactoryReset = false;
    }
}

void ButtonDriver::filterResetButtonCallback(void *handle, void *userData)
{
    ButtonDriver* thisInstance = (ButtonDriver*)userData;
    ESP_LOGI(TAG, "Filter reset button pressed – resetting filter usage counter");
    thisInstance->fanDriver->resetFilterCounter();
}

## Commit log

2026-03-29 Initial skeleton
    [613944ba-fe9f-48cb-8cb3-5e63c1b6e453-onb_codes.csv, cn_dacs-2026-03-29-14-02-49-576517.csv, config.csv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]
2026-03-29 Implement matter fan control with percentage
2026-03-30 Also map panel button
2026-04-01 Turn off fan power at 0 percent
2026-04-01 Implement Thread network signal bars
2026-04-01 Fix animation speed initial state
    [DisplayDriver.hpp]
2026-04-01 Implement Factory Reset screen
    [ButtonDriver.cpp, DisplayDriver.hpp]
2026-04-01 Button behavior: 2s hold: info screen. 8s hold: factory reset
    [ButtonDriver.cpp]
2026-04-01 Better RPM print
2026-04-01 Fix RPM printing
2026-04-02 QR code generation and drawing. Added comission screen with qr code and manual code
    [config.csv, config_tmp.csv, master.csv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]
2026-04-02 Pin u8g2 submodule to specific commit
2026-04-02 Better mfg partition generation scripts
    [partition.csv]
2026-04-03 More README and add hardware files
    [CRBox Front Panel.stl, laser cut bottom.dxf, laser cut left.dxf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]
2026-04-03 Generate different matter credentials, don't use mine
    [613944ba-fe9f-48cb-8cb3-5e63c1b6e453-onb_codes.csv, cn_dacs-2026-04-03-11-28-04-507679.csv, config.csv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]
2026-04-04 Add filters usage counter and filters change button
2026-05-01 Update schematic
2026-05-01 Update laser cut files: put fan on the front
    [laser cut bottom.dxf, laser cut left.dxf, laser cut right.dxf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]
